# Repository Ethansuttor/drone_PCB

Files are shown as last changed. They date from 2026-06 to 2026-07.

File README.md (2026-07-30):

# Custom Drone Flight Controller PCB

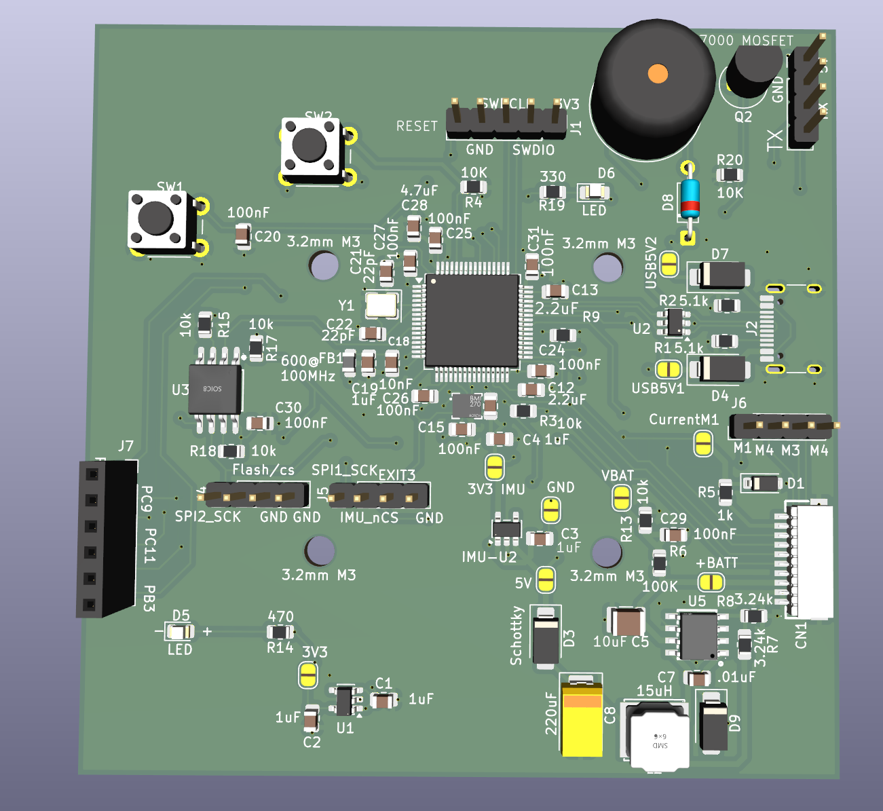
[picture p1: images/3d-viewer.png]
Flight controller PCB, top view


An 80×80 mm STM32F405 flight controller for a 4S freestyle quad, running Betaflight off a custom target I wrote. I built it to find out whether I could take an embedded system from a blank schematic all the way to something that actually flies.

Boards are at JLCPCB. Nothing has been powered on yet, so treat everything below as designed-and-verified-on-paper, not proven.

There's no VTX, camera, or OSD. Those are solved problems, and adding them would have cost layout time I wanted to spend on power architecture, IMU integration, and getting the pinout right.

## Why it looks like this

The biggest constraint was self-imposed: the board has to mate with an ESC I already owned, a Flycolor Raptor BLS-04 4-in-1, using its existing 10-pin harness. That turned out to be the most useful decision I made, because the BLS-04 has no BEC. It hands you raw pack voltage and nothing else. So the board needs its own buck converter running off 16.8 V, which is a much more interesting problem than accepting a regulated 5 V from somewhere else.

The board is oversized on purpose. 80×80 mm with a standard 30.5 mm mounting pattern means it overhangs the stack, which would be silly on a real build. But everything is on the top layer in one hotplate reflow pass, and I hand-place all of it, so the extra room is worth more to me than the elegance.

The STM32F405 was the easy call — native Betaflight support, and writing the custom target is a big chunk of the point.

## Hardware

- MCU: STM32F405RGT6, 168 MHz Cortex-M4F, LQFP-64
- IMU: Bosch BMI270 on SPI1
- Blackbox: GigaDevice GD25Q16E, 2 MB SPI NOR on SPI2
- Input: 4S LiPo, 14.8 V nominal / 16.8 V charged, through the ESC harness
- Buck: TPS5450DDAR, VBAT to 5 V
- Regulators: AP2112K-3.3 for MCU/flash/logic and the IMU's VDDIO; TLV733P-3.3 as a separate quiet rail feeding only the IMU's VDD
- Receiver: FlySky FS-iA6B on i-BUS into UART1
- USB-C for Configurator and DFU
- 4-layer: signal / solid ground / power / signal, ENIG finish
- Spare UART3, USART6 and I2C1 pads for GPS or a mag later

## The parts that went wrong

This is the section I'd actually want to talk about in an interview.

**The IMU disappeared mid-design.** I'd settled on a TDK ICM-42605. Then the entire 426xx family went reel-only at LCSC — minimum orders of a thousand-plus — and out of stock at DigiKey and Mouser. In single quantities it simply stopped existing. The replacement was a Bosch BMI270, which shares the 2.5×3.0 mm LGA-14 outline and nothing else: completely different pinout, new footprint, every IMU net re-routed, different decoupling.

What saved it was a decision I'd made months earlier for unrelated reasons. Splitting the 3.3 V rail in two — a main AP2112K for logic and a dedicated TLV733P for the gyro — meant VDD was already isolated from switching noise. When the part changed, VDD still landed on the quiet rail and VDDIO still landed on the logic rail. A forced sourcing change cost me a footprint and a re-route instead of a power redesign. I'd like to claim I planned for that. I didn't.

The tradeoff is real, though: the BMI270 ships uncalibrated, which is why Betaflight discourages it for new designs, and it caps the PID loop at 3.2 kHz instead of 8 kHz. For Acro freestyle neither matters much. It's still a downgrade I took because the alternative was not building the board.

**I ordered the wrong flash chip.** The BOM called for a 128 Mbit part. A 16 Mbit part arrived — 2 MB instead of 16. I found it a week after the boards shipped, while cross-checking three different BOM files against the firmware, which is a sentence that should tell you something about how I was managing the BOM.

I'm keeping it. Betaflight identifies SPI NOR by JEDEC ID at runtime, and the GD25Q16E is already in the driver's device table, so nothing changes in firmware. What I lose is log duration: about 22 seconds at full rate, or roughly 90 seconds if I drop the blackbox sample rate to 1/4. Since 800 Hz still resolves everything below 400 Hz, where the noise peaks that matter for filter tuning live, and since tuning runs are a minute anyway, the practical cost is that I can't log a whole pack. Every candidate chip shares the same SOIC-8 208-mil footprint, so fixing it later is a hot-air swap.

**A DMA collision moved a motor output.** Motor 4 originally sat on PB7, which wanted DMA1 Stream 3 — the same stream SPI2_RX uses for the blackbox flash. DShot would have fought the logger for it. The final as-built mapping is M1 = PB0 and M2 = PB1 on TIM3, M3 = PA3 and M4 = PB10 on TIM2, checked against RM0090's DMA request mapping table. I'll confirm it with `dma show all` at bring-up rather than trusting the table twice.

## Designed so I can actually bring it up

I assume I've made mistakes I haven't found yet, so the board is built to fail safely and be diagnosed.

Four normally-open solder jumpers split the power tree: buck output to the 5 V rail, 5 V to each LDO, and the quiet 3.3 V rail to the IMU. Each stage comes up on a current-limited bench supply before the next jumper is closed, so a short behind one jumper can't take the STM32 with it.

Test points sit on every rail plus multiple grounds, on the buck's switch and feedback nodes for scoping, and on both ADC sense lines for calibration. There are dedicated ground loops next to the buck and the IMU so a scope probe gets a short ground lead instead of the usual six inches of alligator clip.

Unused STM32 pins are broken out to a labelled header where the layout allowed — timer-capable pins for motor reassignment, a spare UART, spare ADC channels, and SWO. Cheap insurance against a pin-level mistake that would otherwise mean a respin.

One more thing that isn't a jumper: the schematic numbers the ESC connector in the reverse order to the manufacturer's diagram. It's only correct if the connector mates flipped. Before anything gets powered, I continuity-beep VBAT and both grounds from the mated cable to the ESC's XT60. Get that wrong and 16.8 V lands on a 3.3 V GPIO.

## Where it's at

Boards ordered from JLCPCB on 2026-07-19, roughly two weeks out. Bare 4-layer with a frameless top-side stencil, quantity 5. ENIG, mostly so the LGA gyro and the fine-pitch parts solder predictably.

Schematic and layout are done, ERC and DRC both clean. The custom Betaflight target builds. Two BOM questions are still open — whether the TPS5450 or the older TPS5430 actually shipped, and whether the buck inductor is the 15 µH the TI worked example calls for or the 22 µH left over from when this was a 6S design. Both get resolved with a multimeter and a magnifier before I populate anything.

## Next

Paste, populate, hotplate. Then staged bring-up through the jumpers, rail smoke tests, SWD in to flash the target, and motor spin tests with props off. Calibrating the voltage and current ADC scales comes last, since neither is knowable until I can measure them.

Then I find out what I got wrong.

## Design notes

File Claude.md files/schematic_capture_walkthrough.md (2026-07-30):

# Schematic Capture Walkthrough — Drone FC v3

Companion to `drone_fc_project_context_v3.md`. Follow this block by block in KiCad's schematic editor (Eeschema). Capture in this order — power first, MCU core next, peripherals last — so the rails and grounds exist before you hang anything off them.

## KiCad shortcuts you'll use constantly
- `A` — add symbol · `P` — add power symbol · `W` — draw wire · `L` — place net label
- `Q` — place no-connect (×) flag on unused pins · `E` — edit selected symbol/value · `V` — edit value
- `R` rotate · `M` move · `G` drag (keeps wires attached)
- Wires connect by **net name** even without a physical line — use net labels (`L`) liberally instead of dragging long wires across the sheet. Two pins with the same label = same net.

## Global conventions for this board
- **Three supply rails**, each its own power symbol: `+5V`, `+3V3`, `+3V3_IMU`. Grounds all tie to one `GND`.
- Put **decoupling caps physically next to the pin** they serve in layout — but in the schematic just label them clearly (e.g. `C_VDD1`).
- Every power *input* the board generates needs a **PWR_FLAG** (Eeschema → place it on `+5V`, `+3V3`, `+3V3_IMU`, and `GND` once each) or ERC will complain the rails are "driven by nothing."

---

## Capture progress (2026-06-26)
| Block | Status |
|---|---|
| 1 — Onboard buck (TPS5430) | **Done** — fully wired (VIN/Cin, PH+inductor, catch diode, BOOT cap, FB divider, Cout) |
| 1 — USB OR Schottky | **Done** (VBUS→+5V) |
| 2 — Both LDOs (AP2112K + TLV733P) | **Done** — both rails wired |
| 3 — MCU core | Power-in / decoupling reviewed & corrected (caps shunt rail→GND, VDD pins tap +3V3 directly). Clock/boot/SWD still to wire |
| 4 — USB-C | Receptacle (14P symbol), CC pulldowns, Schottky, D±, ESD placed. **Fix outstanding:** USBLC6-2 pin 2→GND and pin 5→VBUS were left floating |
| 5 — ESC connector **J10** | Placed; **VBAT + GND wired, signal/logic lines NOT yet** (M1–M4, CRT current, ESC_TLM) + their ADC protection |
| 6 — IMU power | **Done** (VDD, VDDIO, grounds, RESV, INT2). **IMU SPI logic NOT yet** (SCK/MISO/MOSI/CS/INT) |
| 7 — Flash | Not started |
| 8 — Receiver header / spares | Header placed; logic confirmed (FlySky i-BUS) |
| 9 — Buzzer / LED | Not started |
| 10 — ERC / footprints | Pending |

**Next up:** IMU SPI1 logic lines, J10 signal lines + ADC protection, MCU clock/boot/SWD, flash.

---

## Block 1 — Power input: onboard buck + USB ORing
Goal: generate a clean `+5V` rail **on-board** from the battery (the ESC's raw VBAT), ORed with USB, with no backfeed into USB.

> The BLS-04 / Trinx G20 ESCs have **no BEC** — they only pass raw pack voltage. So the FC makes its own 5V, exactly like a commercial stack FC. `VBAT_RAW` arrives on the ESC 10-pin harness (Block 5) and feeds both the VBAT sense divider *and* this buck.

**Buck — TPS5430DDAR** (`drone_lib:TPS5430DDAR`, ESOP-8, C9864). Pinout: 1 BOOT · 4 VSENSE · 5 ENA · 6 GND · 7 VIN · 8 PH · exposed pad = GND.
- **VIN (7)** ← `VBAT_RAW`. Decouple **2×10µF 50V X7R (GRM32ER71H106KA12L, C77102) + 100nF** from VIN→`GND`, right at the pin. *(50V parts — 6S is 25.2V.)*
- **GND (6)** + **exposed pad** → `GND`.
- **PH (8)** = switch node → one end of the **22µH (≥3A) shielded inductor (CKCS6028-22µH, C354622)**; other end → `+5V`.
- **Catch diode — SS34** (`Diode:D_Schottky`): cathode → `PH`, anode → `GND`.
- **BOOT (1)** → **10nF** cap to `PH`.
- **VSENSE (4)** ← feedback divider: **R1 = 10k** from `+5V` to VSENSE, **R2 = 3.24k** from VSENSE to `GND` (Vref 1.221V → 5.0V).
- **ENA (5)** → leave floating (internal pull-up enables it). *(Optional: a VBAT→ENA resistor divider sets a UVLO turn-on threshold.)*
- **Output cap** on `+5V`: **220µF aluminum-polymer (~20–40mΩ ESR) + 100nF** to `GND`. **Not pure ceramic** — the TPS5430 is internally compensated for some output-cap ESR, so an all-ceramic output can ring/oscillate (use polymer or POSCAP).

**USB OR:**
- **Schottky** SS34/B5819W — anode to USB `VBUS` (Block 4), cathode to `+5V`. ORs USB power onto the rail on the bench, blocks backfeed into USB.

Result: `+5V` comes from the onboard buck in flight and from USB through the Schottky on the bench. Drop a **PWR_FLAG** on `+5V` and on `GND`. *(No external 5V-in connector — that's removed.)*

**Layout note:** keep the buck loop (VIN cap → IC → inductor → catch diode → output cap) tight, the PH switch node small, and the whole thing **away from the IMU and the VBAT/CRT ADC traces**.

## Block 2 — 3.3V rails (two LDOs)
**Main 3.3V — AP2112K-3.3 (C51118, SOT-23-5):**
- VIN ← `+5V`, GND ← `GND`, VOUT → `+3V3`, EN → tie to VIN (`+5V`) so it's always on.
- Input caps: 10µF + 100nF from VIN to GND. Output caps: 10µF + 100nF from VOUT to GND.

**Quiet IMU 3.3V — TLV733P-3.3 (C134139, SOT-23-5):**
- VIN ← `+5V`, GND ← `GND`, VOUT → `+3V3_IMU`, EN → tie to VIN.
- Caps: 1µF in, 1µF out (plus the 100nF that sit at the IMU pins in Block 6).

Drop **PWR_FLAG** on `+3V3` and `+3V3_IMU`. The IMU rail is deliberately separate from everything else for low gyro noise.

---

## Block 3 — STM32F405RGT6 core (the big one)
Place symbol **`MCU_ST_STM32F4:STM32F405RGTx`** (`A`, type STM32F405). Wire its support circuitry:

**Power pins**
- All `VDD` pins → `+3V3`; all `VSS` pins → `GND`. LQFP-64 has four VDD/VSS pairs — put a **100nF next to each** plus one **4.7µF bulk** on `+3V3` near the chip.
- `VDDA` → `+3V3` through the analog filter: **1µF + 10nF** to GND at the pin (optionally a ferrite/small resistor from +3V3 to VDDA). `VSSA` → `GND`.
- `VBAT` pin → `+3V3` with a **100nF** to GND (not using a coin cell; just tie to 3V3).

**VCAP (mandatory — core regulator)**
- `VCAP_1` (pin 31) → **2.2µF X5R/X7R** to GND, placed at the pin.
- `VCAP_2` (pin 47) → **2.2µF X5R/X7R** to GND, placed at the pin.
- Skip these and the chip won't boot reliably.

**Clock (HSE)**
- 8MHz crystal between `PH0`/`OSC_IN` and `PH1`/`OSC_OUT`.
- One load cap from each crystal pin to GND. **Value 22pF** (open item: confirm against the crystal's CL — 22pF suits CL ≈ 12–14pF).

**Boot / reset**
- `BOOT0` → **10k pull-down to GND**, plus a tact switch from BOOT0 to `+3V3` (press = enter DFU).
- `PB2/BOOT1` → **10k pull-down to GND** (must be low for system-memory DFU; floating = unreliable boot).
- `NRST` → tact switch to GND + **100nF** to GND.

**SWD programming header**
- 5-pin header (`Conn_01x05`): `+3V3`, `PA13`/SWDIO, `PA14`/SWCLK, `NRST`, `GND`. Leave PA13/PA14 otherwise unassigned.

---

## Block 4 — USB-C (wired; one ESD fix outstanding)
Place **USB-C receptacle** — schematic uses the KiCad `USB_C_Receptacle_USB2.0_14P` symbol (maps to the TYPE-C-31-M-12, C165948). The 14P is USB-2.0-only and omits the SBU pins, which is correct — this link is only a USB-2.0 device port for DFU + Betaflight config.

- **Reversible-pin shorting:** tie the two `D+` positions together (A6 + B6) and the two `D−` together (A7 + B7) at the connector — Type-C is reversible, so each line is duplicated.
- `VBUS` (A4) → the Schottky anode in Block 1. Tie all VBUS/GND positions on the connector together; don't leave duplicates floating.
- `GND` / shield pins → `GND`.
- `CC1` (A5) → **5.1k to GND**. `CC2` (B5) → **5.1k to GND** (Rd — tells the host this is a device/sink; without these no VBUS).
- `D+` → MCU `PA12`, `D−` → MCU `PA11`. **No series resistors** (F405 has internal impedance per AN4879).
- **ESD — USBLC6-2SC6 (C7519, SOT-23-6)**, placed right at the connector. Force the trace *through* it by renaming across it: connector side `USBC_DP`/`USBC_DM` → device side `USB_DP`/`USB_DM`. Pairing: I/O1 = pins 1 (connector) & 6 (MCU); I/O2 = pins 3 (connector) & 4 (MCU).
  - **FIX OUTSTANDING:** **pin 2 → `GND`** and **pin 5 → `VBUS`** must be connected — they were left floating, which disables the clamp (the steering diodes need both rails). Wire these before ERC.
- **Optional VBUS sense:** 10k/10k divider from `VBUS` to `PC0` (Betaflight `USB_DETECT_PIN`).

## Block 5 — ESC connector **J10** (verified pinout — handle VBAT/CRT with care)
Place the **JST SH 1.0 10-pin** (SM10B-SRSS-TB, C160409, `drone_lib`). **Status (2026-06-26): VBAT + GND wired; signal lines (M1–M4, CRT, ESC_TLM) + their ADC protection still TODO.** Wire per the **verified** table:

| ESC pin | Net | MCU | Protection on the FC side |
|---|---|---|---|
| TX (telemetry) | `ESC_TLM` | `PC7` (USART6 RX) or leave NC | none — non-functional on BLHeli_S |
| CRT (current) | `CURR_SENSE` | `PC2` | **1kΩ in series + 3.3V Zener from PC2 to GND** |
| S1 | `M1` | `PB0` | — |
| S2 | `M2` | `PB1` | — |
| S3 | `M3` | `PA3` | — |
| S4 | `M4` | `PA2` | — |
| NC | — | — | place a no-connect `Q` |
| VBAT | `VBAT_RAW` | `PC1` | **100kΩ/10kΩ divider → PC1, + 100nF from PC1 to GND** |
| GND | `GND` | — | — |
| GND | `GND` | — | — |

- **VBAT divider:** 100k from `VBAT_RAW` to node, 10k from node to GND, node → `PC1`, 100nF node→GND. This scales up-to-25.2V down to ~2.3V max. Without it you put pack voltage on a 3.3V pin.
- **`VBAT_RAW` also feeds the onboard buck (Block 1):** the same harness VBAT net runs to the TPS5430 VIN. The FC's current draw is small, so the harness VBAT line carries it fine — this is how the FC is powered in the air now that the external BEC is gone.
- **Current clamp:** 1k from `CRT` to `PC2`, then a 3.3V Zener from `PC2` to GND. The 1k limits fault current into the clamp.
- Motor nets `M1–M4` go straight to the timer pins; you'll remap S1–S4 order in Betaflight, so exact assignment isn't critical.

---

## Block 6 — IMU (Bosch BMI270) — **DONE** (re-done 2026-07-30, was ICM-42605)

Place **BMI270** (C2836813, `drone_lib`), footprint `LGA-14_L3.0-W2.5-P0.50-BR`.
Datasheet pin map (rev 1.3 Table 22, p.145): 1 SDO · 2 ASDx · 3 ASCx · 4 INT1 ·
5 VDDIO · 6 GNDIO · 7 GND · 8 VDD · 9 INT2 · 10 OCSB · 11 OSDO · 12 CSB ·
13 SCx · 14 SDx.

> ⚠ **Do not reuse the 426xx wiring from an earlier revision of this doc.** The
> BMI270 shares only the package *outline* — pin functions are completely
> different, and two of the old habits are now actively wrong (see the strapping
> bullet below).

**Power — split rails, unchanged from the 42605 design:**
- `VDD` (pin 8) → **`+3V3_IMU`** (quiet TLV733P rail, via **JP10**), **100nF** at the pin. Noise-sensitive analog/MEMS supply. Range 1.71–3.6V.
- `VDDIO` (pin 5) → **`+3V3`** (main logic rail — NOT the quiet rail), **100nF** at the pin. Carries digital I/O switching noise and sets the SPI logic level, so it rides the host rail. Range 1.2–3.6V.
- **Decoupling is 100nF × 2 only** — the 2.2µF/0.1µF/10nF arrangement was a 426xx datasheet requirement and does not apply.
- `GNDIO` (6) and `GND` (7) → `GND`.

**Unused-pin strapping — different from the 42605, get this right:**
- `ASDx` (2) and `ASCx` (3) → **`VDDIO`**. Datasheet note ** is explicit: if the secondary interface is unused these may go to VDDIO or be left open, but **do not connect to GND**. (The 42605's RESV-to-GND habit would be a mistake here.)
- `INT2` (9), `OCSB` (10), `OSDO` (11) → **do not connect**. Note *** allows OCSB/OSDO to GND only if `IF_CONF.ois_en = 0`; leaving them open is safer.
- There is **no** mandatory-ground RESV pin on this part.

**SPI1 logic:**
- `SCx` (13) → `PA5`, `SDO` (1) → `PA6`/MISO, `SDx` (14) → `PA7`/MOSI.
- `CSB` (12) → `PC4`, **plus a 10k pull-up to `+3V3`** (= VDDIO). Holds CS high through boot/DFU. Note the pull-up is to the *host* rail, matching the SPI logic level.
- `INT1` (4) → `PC3` (EXTI3) — keep this trace short in layout.
- **SPI clock ≤10MHz** for the BMI270 (Betaflight's `BMI270_MAX_SPI_CLK_HZ`). This is a real tightening from the 42605's 24MHz — the old "/4 = 21MHz" advice is no longer valid.
- Protocol note: the BMI270 powers up in **I2C** mode and only switches to SPI after seeing a **rising edge on CSB** (datasheet §"protocol selection"). The 10k pull-up holds CSB high through POR; Betaflight's driver toggles CS to make the transition. Only matters if you drive the chip from bare STM32 code.
- Layout note (not schematic): IMU dead-center, axes aligned to the frame, solid ground under it.

## Block 7 — Blackbox flash (SPI2) — **as-fitted part is GD25Q16E, 2 MB**
Place **GD25Q16E** (C2904431, SOIC-8 208mil). Powered from `+3V3`.

> ⚠ **Two corrections vs. earlier revisions of this doc:**
> 1. The part is **not** a W25Q128JVSIQ (C97521, superseded on MOQ) and **not**
>    the BY25Q128ESSIG the BOM specified. The chip actually ordered and fitted is
>    a **GigaDevice GD25Q16E — 16 Mbit = 2 MB, one eighth the intended capacity.**
>    Kept deliberately; see `VERIFIED_PINOUT.md` § Blackbox flash.
> 2. **MISO is on `PC2`, not `PB14`.** The old line below was wrong and is
>    contradicted by the as-built schematic.

- `VCC` → `+3V3` with **100nF**. `GND` → `GND`.
- SPI2: `CLK` → `PB13`, `DO`/MISO → **`PC2`**, `DI`/MOSI → `PB15`.
- `CS` → `PB12`.
- `/WP` and `/HOLD` → tie to `+3V3` (disabled) unless you have a reason not to.
- Footprint is SOIC-8 208mil, shared by every candidate part (W25Q128, BY25Q128ES,
  GD25Q16E, GD25Q128E) — so a capacity upgrade is a hot-air swap, no layout change.
- Betaflight needs no code change for the 2 MB part: `USE_FLASH_W25Q128FV` only
  gates the generic `m25p16` driver, which detects by JEDEC ID at runtime.

---

## Block 8 — Receiver header & spare pads
- **Receiver header** (4-pin `Conn_01x04`): `+5V`, `GND`, `TX`=`PA9` (UART1 TX), `RX`=`PA10` (UART1 RX). **Receiver = FlySky FS-iA6B → use i-BUS** (single serial wire on UART1 RX). i-BUS is non-inverted, so it connects straight to RX — **no inverter needed**. *(Reject S.BUS: it's inverted and the F405 has no internal UART inverter — would need an external transistor.)* PA10 is a 5V-tolerant (FT) pin, good since the iA6B is powered at 5V. TX pin is for optional i-BUS telemetry later. Betaflight: Serial RX on UART1, provider = IBUS. **Power pin = 5V** (iA6B input range 4.0–8.4V; never battery). One 3-wire run (5V/GND/RX) to the receiver's i-BUS port both powers it and carries data.
- **Spare UART3 pads:** `PB10` (TX), `PB11` (RX) — future GPS/MSP.
- **Spare USART6 pads:** `PC6` (TX), `PC7` (RX) — note PC7 may also carry the ESC `ESC_TLM` net if you wired it in Block 5; pick one use.
- **Spare I2C1 pads:** `PB6` (SCL), `PB7` (SDA) — future baro/mag. Add 4.7k pull-ups to `+3V3` on each if you expect to use them.

## Block 9 — Buzzer & status LED
**Buzzer (hand-soldered, DNP in JLC BOM):**
- `PC5` → gate of **2N7002** (via the gate; source to `GND`).
- Buzzer `+` pad → `+5V`; buzzer `−` pad → 2N7002 drain. Place **1N4148 flyback** across the buzzer (cathode to +5V, anode to drain).
- Use the SUN-12095 footprint (C360615) for the pads but mark the buzzer **DNP** so JLC skips it.

**Status LED:**
- `PB8` → **330Ω** → LED anode; LED cathode → `GND` (or wire active-low to +3V3 if you prefer — just be consistent in config). Avoid PC13 (forbidden — power-switch domain).

---

## Block 10 — Finish & check
1. **Place PWR_FLAGs** (once each) on `+5V`, `+3V3`, `+3V3_IMU`, `GND` if not already.
2. **No-connect (`Q`)** every genuinely unused MCU pin and the ESC `NC` pin, or ERC will warn.
3. Run **Inspect → Electrical Rules Checker (ERC)**. Resolve real errors (unconnected pins, conflicting outputs). Expect a few "unconnected" warnings on spare pads — those are fine to leave or no-connect.
4. **Annotate** (assign reference designators) and **assign footprints** (Tools → Assign Footprints): your `drone_lib` parts already carry footprints; assign standard 0402/0603 footprints to passives and attach their LCSC part numbers in the symbol's field (this drives the JLC BOM later).
5. Save, commit to your `.history` git, and only then move to PCB layout.

## Order of attack (so grounds/rails exist first)
Power (1–2) → MCU core + VCAP + clock + boot (3) → USB-C (4) → ESC connector + ADC protection (5) → IMU (6) → flash (7) → headers/spares (8) → buzzer + LED (9) → ERC (10).

## Watch-outs
- VCAP caps and the VBAT-pin 100nF are easy to forget and both cause "won't boot" symptoms.
- The VBAT divider and CRT Zener are safety-critical — never wire ESC VBAT/CRT straight to a GPIO.
- IMU rails are split on purpose: **`VDD` (pin 8) on `+3V3_IMU`** (quiet), **`VDDIO` (pin 5) on `+3V3`** (host logic rail). Don't put VDD on the main rail or VDDIO on the quiet rail.
- **USBLC6-2 pin 2 → `GND`, pin 5 → `VBUS`** — if either floats the ESD array does nothing (caught this in the draft).
- Single ground only — there is no separate "digital"/"power" GND net. Everything returns to one `GND` pour (L2); isolation is by split *power* rails + layout, not split grounds.
- Receiver header power pin = **5V**. Use the 5V-tolerant RX pin (PA10) for the i-BUS signal.
- Buck **input caps must be ≥50V** (6S = 25.2V); keep the buck switch node/loop tight and away from the IMU and ADC lines, or it shows up as gyro noise.
- The FC has **no external 5V input anymore** — power comes from `VBAT_RAW` (ESC harness) through the onboard TPS5430 buck.

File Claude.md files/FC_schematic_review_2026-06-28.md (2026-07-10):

# Schematic Error Review — Drone FC (2026-06-28)

**Scope:** schematic only, pre-layout. **Method:** geometric netlist extracted from the `.kicad_sch` s-expressions (pin coords transformed by each symbol's rotation/mirror, unioned with wires/junctions/global-labels/power-symbols). Calibrated transform: 190/227 pins land on a connection point; power/VCAP/USB/SPI all resolve correctly, so connectivity is reliable. Pin functions re-checked against DS8626 (STM32F405 LQFP-64), the ICM-42605 and TPS5430 datasheets.

> **Source-of-truth note:** the working files in `Drone_PCB_FC/` are **corrupt** (see #0). This review was run on the newest intact backup: `Drone_PCB_FC-backups/Drone_PCB_FC-2026-06-27_204112.zip` (2026-06-27 20:41 local) — which is *newer* and more complete than the corrupted working copy.

---

## 0. FILE CORRUPTION — fix before anything else
`MCU-STM32F405.kicad_sch` and `LDOs.kicad_sch` on disk are **truncated mid-write** (unbalanced parens — MCU ends mid-`C13` property). The other sheets are intact but **NUL-padded**. The stale `~*.lck` files (dated Jun 25) mean KiCad exited ungracefully and a save got mangled (looks like a sync/crash). The working `.kicad_sch` files also carry an *older* mtime (11:42) than the latest backups (through 20:41), so they're both corrupt **and** stale.

**Fix:** Don't fab or ERC from the working folder as-is. Open the project in KiCad — if it loads clean, immediately `File → Save` (overwrites the corruption). If it errors on load, restore from `Drone_PCB_FC-2026-06-27_204112.zip`. Nothing newer than 20:41 was lost (the corrupt files are older content).

---

## CRITICAL / safety

### C1 — ESC connector CN1 is wired in REVERSE pin order vs your verified harness table  ⚠️ 25 V-onto-GPIO risk
Extracted CN1 signal pins (1→10): `GND, GND, +BATT, NC, M4(TIM4_CH2), M3(TIM4_CH1), M2(TIM3_CH4), M1(TIM3_CH3), CURR, NC`. (Pins 11/12 = shield → GND, fine.)
Your `schematic_capture_walkthrough.md` Block 5 table says pin1=TX, pin2=CRT, pin3=S1 … **pin8=VBAT**, pin9/10=GND. The schematic is that table **flipped end-for-end** — VBAT sits on CN1 pin 3, and a motor GPIO (PB0) sits on CN1 pin 8.

This is only correct if your ESC cable is a **reversed/crossover** SH1.0 type (or the footprint's pin-1 pad is at the far end). With a **straight 1:1 cable** + same-handed footprint, harness VBAT (ESC pin 8, up to **25.2 V** on 6S) lands on **CN1 pin 8 = PB0 = TIM3_CH3**, a 3.3 V GPIO → **instant MCU death**. Also CRT and TX would short to GND.

**This cannot be settled from the schematic.** Resolve it two ways, both:
1. Make the schematic match your documented intent (TX on pin 1 … VBAT on pin 8), *or* explicitly confirm the footprint pin-1 + reversed cable and update the Block-5 table so it's not contradictory.
2. **Before first power-up** do the continuity beep test (open item #1): VBAT + both GNDs from the *mated cable* to the ESC XT60 pads.

### C2 — Current-sense line has NO protection (required) and is on the wrong ADC pin
`CURR` net = `{CN1.9, U4.9/PC1}` only. The ESC CRT output runs **straight into PC1 (ADC123_IN11)** — no 1 kΩ series resistor, no 3.3 V Zener clamp. Your context doc marks "1 kΩ series + 3.3 V Zener clamp (**required**)" on this line; the walkthrough put it on PC2. Neither part exists in the netlist (no 1 kΩ R, no Zener anywhere in the BOM).
**Fix:** insert 1 kΩ in series CN1.9→ADC, add a 3.3 V Zener (or 3.3 V TVS) from the ADC node to GND, + ~100 nF. Pick PC1 *or* PC2 and set it in the target; PC2 is currently free.

### C3 — No VBAT voltage-sense divider exists (no battery voltage telemetry)
`+BATT` = `{CN1.3, U5.7 (buck VIN), C5.1}` — battery reaches the buck only. There is **no 100k/10k divider to any ADC pin** (PC0 and PC2 are free, both unconnected). Betaflight will have current sense but **no pack-voltage reading** → no voltage alarms, no sag compensation.
**Fix:** add 100 kΩ/10 kΩ from `+BATT` to a free ADC pin (PC0 = ADC123_IN10, or PC2) + 100 nF to GND. 100k/10k → 2.29 V at 25.2 V, safe; set `vbat_scale ≈ 110`.

---

## MAJOR / functional

### M1 — IMU VDD / VDDIO rails are SWAPPED (defeats the dedicated quiet LDO)
Extracted: `U6.8 VDD → +3V3` (main/noisy), `U6.5 VDDIO → +3V3_IMU` (quiet TLV733P). Decoupling follows the wrong rails (C10 2.2 µF + C11 0.1 µF on VDD/main; C9 10 nF on VDDIO/quiet).
This is **backwards from your own locked decision** (context v3, 2026-06-26: "VDD (pin 8) stays on the quiet +3V3_IMU … VDDIO (pin 5) now sits on the main +3V3"). Per the ICM-42605 datasheet, **VDD** is the device/MEMS/analog supply (the noise-sensitive one); **VDDIO** is just digital-I/O level. As drawn, the gyro's analog supply rides the shared MCU/flash rail and the clean LDO is wasted on the I/O pin → worse gyro noise floor.
**Fix:** swap the rails — VDD (pin 8) + C10 + C11 → `+3V3_IMU`; VDDIO (pin 5) + C9 → `+3V3`. (Also move the CS pull-up R3 to match VDDIO's rail.)

### M2 — Buck inductor value mismatch: schematic 15 µH vs locked BOM part 22 µH
`L2 = 15 µH` (symbol `Device:L_Iron`). Your locked BOM inductor is **22 µH, CKCS6028-22µH, LCSC C354622**. 15 µH is electrically valid (TPS5430 datasheet design example uses 15 µH, KIND=0.2, L_min≈12.5 µH; for 5 V/3 A/6S L_min≈13 µH), but the **schematic value and the part you'll order disagree** — the generated BOM would call out 15 µH.
**Fix:** set `L2 = 22 µH` to match C354622 (lower ripple, gentler), or re-spec the BOM to a 15 µH ≥3 A shielded part. Either way reconcile. (`L_Iron` is just a cosmetic symbol — assign the real shielded-inductor footprint.)

### M3 — Motor 4 (PB7/TIM4_CH2) DMA collides with blackbox SPI2_RX
Motors map PB0=TIM3_CH3 (DMA1 S7), PB1=TIM3_CH4 (S2), PB6=TIM4_CH1 (S0), **PB7=TIM4_CH2 (DMA1 S3)**. Flash SPI2_RX is also **DMA1 Stream 3** (RM0090 Table 42). They can't both run a DMA at once. Usually survivable (blackbox *writes* use SPI2_TX/S4; log download happens disarmed), but it constrains the custom target and can break DMA flash reads while armed.
**Fix (clean, optional):** move motor 4 to **PB5 = TIM3_CH2 (DMA1 S5)** — conflict-free vs all other motors, SPI2 and SPI1. PB5 is currently free.

---

## COMPLETENESS — the schematic is not finished
These blocks from your walkthrough are simply not in the netlist yet. Don't start layout until they're in, or you'll re-spin:

- **No SWD header.** PA13/PA14 dangle on unnamed stub nets; no `Conn` for SWD exists. You'd be DFU-only with no debugger. Add the 5-pin header (3V3/SWDIO PA13/SWCLK PA14/NRST/GND). *(Block 3)*
- **No buzzer circuit.** PC5 is a bare stub — no 2N7002, no buzzer pads, no 1N4148. *(Block 9)*
- **No status LED.** PB8 is a bare stub — no LED, no 330 Ω. *(Block 9)*
- **No spare UART3/USART6/I2C1 pads** (PB10/PB11, PC6/PC7, PB6/PB7). Optional, but they were in the plan. *(Block 8)*

## HOUSEKEEPING / BOM hygiene

- **`C1` value = `C1uF`** (malformed) → set to `1uF`. *(LDOs)*
- **`Y1` value = `Crystal_GND24`** (symbol name, not a value) → set `8 MHz` and assign a real crystal + confirm CL vs the 22 pF load caps (open item #2). *(MCU)*
- **`D3`/`D4` value = `D_Schottky`** (generic) — these are the USB-OR diodes; assign a real part (SS34/B5819W). *(LDOs)*
- **Battery-rail cap ratings unspecified.** `C5` (10 µF on +BATT) and any +BATT ceramic must be **≥50 V for 6S** (25.2 V). Plan called for **2×10 µF**; only one (C5) is placed. Add a 100 nF HF cap at VIN. `C8` (220 µF out) needs ≥10 V; it's correctly a polymer (`C_Polarized`) — keep it non-ceramic for TPS5430 loop stability.
- **Many unused MCU pins** sit on unnamed nets — add no-connect (`Q`) flags or ERC will bury real errors in warnings.
- **5 V rail is actually ~4.6 V:** both the buck (+5V_Buck) and USB (+5V_USB) feed +5V through Schottkys (D3/D4), so the receiver/buzzer see ≈4.6 V. Fine (FS-iA6B wants 4.0–8.4 V), just be aware. FB correctly taps +5V_Buck (pre-diode), so the buck still regulates a true 5.0 V.

---

## Already CORRECT / fixed since the 2026-06-27 review (don't re-touch)
- **VDDA** now properly filtered: `+3V3 → FB1 (600 Ω) → VDDA`, C18 (10 nF) + C19 (1 µF) VDDA→GND. (The old VDDA-to-GND short is gone.)
- **Both VCAP caps present:** C12 (2.2 µF) on VCAP_1, C13 (2.2 µF) on VCAP_2, each to GND.
- **Buck feedback R8 = 3.24 kΩ** (was the dangerous bare "3.24"); Vout = 1.221·(1+10k/3.24k) = 5.0 V. ✓
- **Receiver J3 wired:** Pin3→UARTx_RX→PA10, Pin4→UARTx_TX→PA9, Pin1→+5V, Pin2→GND (USART1, non-inverted i-BUS). ✓
- **USBLC6-2 fixed:** pin 2→GND, pin 5→VBUS(+5V_USB); D±routed *through* the array to PA11/PA12. ✓
- **VDD decoupling:** 4×100 nF (C24–C27) + 4.7 µF (C28) for the four VDD pins; VBAT pin1→+3V3. ✓
- IMU SPI1 (PA5/6/7, CS=PC4 + R3 pull-up, INT=PC3), flash SPI2 (PB12–15), crystal on PH0/PH1 w/ 22 pF, BOOT0/BOOT1/NRST straps — all correct.

---

## Verdict: **Proceed with changes — do not start layout yet**
The power core, MCU support, USB, SPI buses, clock and boot straps are clean, and the three old fab-blockers are fixed. But: **C1 (ESC pin-order / VBAT-on-GPIO)** is a genuine brick-the-board risk that must be resolved + continuity-verified, **C2/C3** leave required ADC protection and battery sensing missing, **M1** (IMU rail swap) wastes your quiet LDO, and the board is **functionally incomplete** (no SWD/buzzer/LED). Fix C1–C3 and M1–M2, finish the missing blocks, restore the file from backup, then run ERC and re-check before layout.

**Order:** #0 file restore → C1 → C2 → C3 → M1 → M2 → SWD/buzzer/LED → BOM values → ERC.

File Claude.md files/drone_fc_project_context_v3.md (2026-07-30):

# Custom Drone Flight Controller PCB — Project Context v3

**Date:** 2026-06-09. Supersedes v1 (`drone_fc_project_context.md`) and the lost v2. Incorporates the June 2026 audit (`FC_audit_2026-06-09.md`). Build is a **bench/resume project: no VTX, camera, or OSD**.

> ### ⚠ Update 2026-07-30 — IMU CHANGED: ICM-42605 → Bosch BMI270
>
> **Every ICM-42605 / ICM-42688-P / 426xx reference below this box is superseded.**
> The board is built around the **Bosch BMI270** (U7, LCSC C2836813, footprint
> `drone_lib:LGA-14_L3.0-W2.5-P0.50-BR`). The 2026-06-23 decision recorded below
> ("BMI270 evaluated and rejected", "stay with the ICM-42605 default") was
> **reversed on sourcing grounds**: the entire TDK 426xx family went reel-only
> (MOQ 1000+) or out of stock in single quantities at LCSC, DigiKey and Mouser.
>
> It is **not a drop-in.** Same 2.5×3.0mm LGA-14 outline, completely different
> pinout → new footprint and every IMU net re-routed. Decoupling is simpler:
> **100nF at VDD + 100nF at VDDIO**, not the 2.2µF/0.1µF/10nF the 426xx wanted.
> The unused-pin strapping is also different — ASDx(2)/ASCx(3) go to **VDDIO**
> and must *not* be grounded, and INT2(9)/OCSB(10)/OSDO(11) are left
> **unconnected**, where the 42605's RESV pins went to GND.
>
> **The power architecture did not change at all** — VDD still on the quiet
> TLV733P `+3V3_IMU` rail, VDDIO still on the main AP2112K `+3V3`. That's the
> payoff of the rail-split decision: a forced sourcing change cost a footprint
> and a re-route, not a power redesign.
>
> Firmware: Betaflight define is `BMI270`. **PID loop ceiling drops to 3.2 kHz**
> (BF clocks the BMI270 gyro at 3.2 kHz ODR; chip max is 6.4 kHz), SPI clock
> ceiling is **10 MHz** not 24 MHz, and the driver uploads an ~8 KB init blob at
> every boot. The BMI270 also ships uncalibrated — a few percent attitude error
> in Angle/Horizon, irrelevant in Acro. `GYRO_1_ALIGN` must be re-derived.
>
> Canonical pad-by-pad wiring table (verified against BMI270 datasheet rev 1.3
> Table 22, p.145): see **`VERIFIED_PINOUT.md` § IMU**.

**Update 2026-07-11 (SCHEMATIC COMPLETE — verified, entering layout):**
Full netlist re-verified pin-by-pin against the KiCad files (not the docs) this session. Status: **schematic done, ERC-clean pending, ready for layout.** Resolutions since 2026-06-28:
- **IMU rail swap DONE** — as-drawn is now correct: VDDIO (pin 5) → +3V3 (main), VDD (pin 8) → +3V3_IMU (quiet). All 14 ICM-42605 pins verified: MISO/MOSI/SCLK/CS on 1/14/13/12, INT1 (4) → PC3/EXTI3, RESV pin 7 + RESV 2/3/10/11 + INT2/FSYNC (9) → GND, CS 10k pull-up → +3V3. Decoupling: VDD 2.2µF+0.1µF, VDDIO 10nF.
- **Current-sense protection ADDED** — CN1 current pin → R5 1k series → PC1, D1 3.3V zener PC1→GND. Correct clamp (PC1 taps between R5 and zener). **Note: current sense is on PC1** (not PC2 as older pin table said).
- **VBAT divider ADDED** — +BATT → R6 100k → PC2, R13 10k + C29 100nF → GND. Ratio 0.091 (16.8 V → 1.53 V at PC2). Battery telemetry now available; calibrate vbat_scale at bring-up.
- **SWD header ADDED (J1, 5-pin)** — 3V3 / SWDIO=PA13 / SWDCLK=PA14 / GND / NRST. For emergency flash/debug if USB DFU fails.
- **Power LED ADDED** — +3V3 → R14 series resistor → D5 → GND. (Earlier IMU-rail LED D6 removed — do not load the quiet gyro rail.)
- **Buck confirmed complete** — TPS5430, L 15µH, Cin 10µF, Cout 220µF polymer, SS34 catch diode, 10nF BOOT cap, FB 10k/3.24k tied to +5V_Buck output. ENA left floating (TPS5430 enables when floating).
- **ORing diodes D3/D4 verified correct** (anodes at +5V_Buck / +5V_USB sources, cathodes at common +5V).
- **Motor pins confirmed in KiCad**: M1=PB0, M2=PB1, M3=PB6 (TIM4_CH1), M4=PB5 (TIM3_CH2). PA2/PA3/PB7 free.

**⚠ REMAINING BEFORE FAB (physical/process, not schematic):**
1. **ESC connector orientation** — CN1 is numbered reverse vs the manufacturer diagram (VBAT on pad 3, GND pads 1–2, current pad 9). Signal order matches the harness only if the connector mates reversed. **Mandatory: continuity-beep VBAT + both GND pads to the ESC XT60 before first power-up** — a mirror error puts 16.8 V on a 3.3 V GPIO.
2. Run **ERC** to zero before layout (authoritative check for unconnected nets).
3. Buzzer (PC5) and Betaflight status LED (PB8) intentionally not populated — spare UART/I2C pads (PB10/11, PC6/7) not broken out. All optional; add if wanted.
4. **File-sync corruption risk** — keep the project OFF the synced drive or pause sync while editing; a truncated `.kicad_sch` right before Gerber export is the worst-case. Confirm clean saves.

**Update 2026-06-28 (battery → 4S, motor remap, open items):**
- **Battery changed to 4S (14.8 V nominal / 16.8 V full charge)** — was 6S. Consequences: buck output inductor is now **15 µH** (TPS5430 datasheet value for this Vin/Vout; L_min ≈ 12 µH) — **the locked BOM 22 µH part C354622 is superseded; order a 15 µH ≥3 A shielded inductor instead.** Battery-rail/buck-input cap voltage rating requirement relaxes from ≥50 V (6S) to **≥25 V (use ≥35 V for transient margin)**. Any VBAT sense divider scales for 16.8 V.
- **Motor remap (done in schematic):** M4 moved **PB7 → PB5 (TIM3_CH2)** to clear the DMA1-Stream3 clash with SPI2_RX (blackbox). Motors are now M1=PB0/TIM3_CH3, M2=PB1/TIM3_CH4, M3=PB6/TIM4_CH1, M4=PB5/TIM3_CH2 → DMA1 streams S7/S2/S0/S5, all clear of SPI2 (S3/S4). PB7 freed. Verified against RM0090 Table 42.
- **IMU rail swap STILL PENDING in schematic:** as drawn, VDD(pin 8)→+3V3 and VDDIO(pin 5)→+3V3_IMU — **backwards** from the 2026-06-26 decision below. Must swap to VDD(8)→+3V3_IMU (quiet), VDDIO(5)→+3V3 (main). Caps follow their pins (C10 2.2µF + C11 0.1µF on VDD; C9 10nF on VDDIO).
- **Still open (ADC protection):** current sense (PC1) needs **1 kΩ series + 3.3 V Zener** to GND; **add a VBAT divider** (e.g. 100k/10k → free ADC PC0 or PC2, +100 nF) if battery voltage telemetry is wanted.
- **⚠ File corruption:** the working `*.kicad_sch` files keep getting truncated/NUL-padded on save (folder-sync race during KiCad's atomic save). The reliable clean copies are the `Drone_PCB_FC-backups/*.zip`. Fix the sync (pause it while editing, or move the project off the synced drive) and confirm a clean save before fab.

**Update 2026-06-26 (schematic capture in progress):** Buck (TPS5430) **fully wired**; both LDOs (AP2112K + TLV733P) **wired**; USB-C wired; **IMU power wired** (SPI logic still to do); ESC connector **J10** has VBAT+GND wired (signal lines pending). Two decisions refined this session: **(1) IMU rail split** — `VDD` (pin 8) stays on the quiet `+3V3_IMU`, but **`VDDIO` (pin 5) now sits on the main `+3V3`** (host logic rail) so digital I/O switching noise stays off the gyro supply and VDDIO matches the SPI host level. Caps per ICM-42605 BoM: 0.1µF+2.2µF at VDD, 10nF at VDDIO; RESV pin 7→GND mandatory, other RESV + INT2/FSYNC→GND. **(2) Receiver = FlySky FS-iA6B over i-BUS** (non-inverted, straight to UART1 RX; S.BUS rejected — inverted, no internal F405 inverter). Also confirmed: LQFP-64 has **no PDR_ON / no BYPASS_REG** pin (regulator + internal reset always on — nothing to wire); no 32.768kHz LSE needed (Betaflight doesn't use RTC). **Open ESD fix:** USBLC6-2 pin 2→GND, pin 5→VBUS were floating in the draft.

**Update 2026-06-23 (decisions locked):** Board grows to **~60×60mm** (oversized bench board for easy hand assembly; retains 30.5×30.5mm M3 mount to mate the BLS-04). **Assembly changed to self-reflow** — order **bare 4-layer PCBs + frameless stencil** from JLC (not PCBA), keep **all SMD single-sided (top)** for one hotplate pass, leaded (Sn63/Pb37) paste, hot-air station for LGA/rework. **MCU order part = STM32F405RGT6TR** (tape-and-reel/cut-tape, LCSC C15742, 600 in stock, buy-1). **IMU resolved — stay with the ICM-42605 default** (LCSC C2655099, buy-1 cut-tape, ~$9.38, ~1,168 in stock): Betaflight-preferred and shares the LGA-14 426xx footprint, so no design change. **BMI270 rejected** — Betaflight discourages it for new designs (uncalibrated gyro, 5–10% attitude error). ICM-42688-P (C1850418) stays as the drop-in alternate if its reel frees up. **Power architecture changed:** the external Matek MBEC6S is dropped — the FC now carries its **own onboard buck (TPS5430DDAR, C9864, VBAT→5V/3A)** fed from the ESC-harness VBAT, because the BLS-04 / Trinx G20 ESCs have no BEC. The old J5 external-5V-in header is removed.

## Project Goal
Custom ~60×60mm flight controller (oversized bench board for hand assembly; 30.5mm M3 mount retained) around the STM32F405RGT6, running Betaflight via a custom target (`config.h`), driving the existing Flycolor Raptor BLS-04 4-in-1 ESC through its original 10-pin harness.

## Open items (blocking schematic)
1. ~~ESC harness pinout UNVERIFIED~~ **RESOLVED 2026-06-16** — manufacturer pinout diagram obtained; cross-checks against the old v1 candidate (same physical layout, opposite numbering). See verified table below. Remaining: 30-sec continuity beep on VBAT + 2×GND to ESC XT60 pads to confirm pin-1 orientation isn't mirrored before first power-up.
2. Crystal load caps: confirm 22pF against the chosen crystal's CL spec (22pF fits CL≈12–14pF with ~2–3pF stray; CL=18pF would need ~30pF).

---

## Hardware Stack

### ESC — Flycolor Raptor BLS-04 4-in-1 (owned)
- BLHeli_S, EFM8BB21-family ESC MCU (per Flycolor S-Tower manual) → **Bluejay-flashable** for bidirectional DSHOT / RPM filtering (verify layout in ESC-Configurator first)
- 3–6S LiPo, 60–65A continuous / 70A burst, 500k eRPM limit
- DSHOT150/300/600, OneShot125/42, Multishot
- **No BEC** — exposes raw VBAT only
- **No serial telemetry** (BLHeli_S limitation; RPM comes via bidir DSHOT after Bluejay)
- 30.5×30.5mm M3 mounting (tower stack — matches FC hole pattern)
- FC interface: 10-pin JST SH1.0

### ESC connector — VERIFIED pinout (manufacturer diagram, 2026-06-16)
From the BLS-04 pinout diagram. Cross-checks against the v1 candidate (identical physical layout — GND/GND/VBAT cluster at one end, CRT/TX at the other, 4 motor signals in the middle — just numbered from the opposite end). Listed in diagram order (one end → other).

| Signal | FC destination | Protection |
|----|----|----|
| TX (ESC telemetry TX) | spare UART RX pad (USART6 RX = PC7) or NC | none — **non-functional on BLHeli_S** (RPM via bidir DSHOT after Bluejay) |
| CRT (current sense, analog) | PC2 (ADC123_IN12) | **1kΩ series + 3.3V Zener clamp (required)** |
| S1 (motor 1) | PB0 | — |
| S2 (motor 2) | PB1 | — |
| S3 (motor 3) | PA3 | — |
| S4 (motor 4) | PA2 | — |
| NC | — | — |
| VBAT (raw pack +, up to 25.2V/6S) | PC1 (ADC123_IN11) **+ TPS5430 buck VIN** | **100k/10k divider + 100nF (sense); also feeds onboard buck input via 50V caps (required)** |
| GND | Ground plane | — |
| GND | Ground plane | — |

**Pre-power continuity check (battery disconnected):** beep from the cable's VBAT and both GND pins to the ESC XT60 pads to confirm pin-1 orientation matches the FC footprint (1:1 SH1.0 cable mirrors pin order; a mirrored connector puts up to 25.2V on a 3.3V GPIO). Motor order (S1–S4) needs no verification — remapped in Betaflight.

### Power
```
LiPo (3–6S, ≤25.2V) → BLS-04/Trinx ESC → raw VBAT on 10-pin harness
   VBAT ─┬─→ sense divider 100k/10k → PC1 (ADC)
         └─→ TPS5430DDAR buck (VBAT→5V, 3A) ─┬─ 5V rail
USB-C VBUS → Schottky (SS34/B5819W) ─────────┘
5V rail → AP2112K-3.3 (600mA) → 3.3V: MCU, flash, LED, logic, BMI270 VDDIO (pin 5)
5V rail → TLV733P-3.3 (LCSC C134139) → [JP10] → 3.3V_IMU: BMI270 VDD (pin 8) only — dedicated quiet rail
5V rail → receiver header (FS-iA6B, 5V), active buzzer
```
- **Onboard buck (NEW 2026-06-23): TPS5430DDAR (LCSC C9864), 5.5–36V in → 5V/3A**, fed from the ESC-harness VBAT. Replaces the external Matek MBEC6S (removed) — the BLS-04 / Trinx G20 ESCs have **no BEC**, so the FC must make its own 5V like a normal stack FC. Support parts (locked to TI datasheet values): **22µH ≥3A shielded inductor (CKCS6028, C354622)**, **SS34 catch diode (PH→GND)** (= datasheet B340A), 10nF BOOT cap, feedback **R1=10k / R2=3.24k** (Vref 1.221V → 5.0V), input **2×10µF 50V X7R (GRM32ER71H106KA12L, C77102)**, output **220µF aluminum-polymer (~20–40mΩ ESR) — NOT pure ceramic** (the TPS5430 is internally compensated for some output-cap ESR; all-ceramic output can oscillate).
- **6S input caps must be ≥50V rated** (25.2V rail). Keep the buck switching loop (input cap → IC → inductor → diode) physically tight and the PH/switch node **away from the IMU and the VBAT/current ADC traces**; the TLV733P then filters residual switching ripple off the gyro rail.
- Schottky ORing lets USB power the MCU + receiver on the bench; the onboard buck dominates in flight. No backfeed into USB.
- AP2112K: 1µF in, 1µF out (ceramic X7R or X5R per datasheet Note 4). EN tied to 5V rail — always-on (VIH max = 6.0V, so 5V is safe). TLV733P: 1µF in/out + 100nF at IMU pins.

---

## MCU — STM32F405RGT6**TR**, **LQFP-64** (10×10mm, 0.5mm pitch; order LCSC C15742 — tape-and-reel/cut-tape, 600 in stock, buy-1)
Required support circuitry:
- 8MHz crystal (HSE) + 2× load caps (size per CL — open item 2)
- Decoupling: 100nF per VDD pin + one 4.7µF bulk; 1µF+10nF on VDDA
- **VCAP_1 (pin 31) and VCAP_2 (pin 47): 2.2µF X5R/X7R each, placed at the pin** (core regulator stability — mandatory)
- MCU VBAT pin → 3.3V + 100nF
- BOOT0: 10k pull-down + button to 3.3V (DFU entry)
- **BOOT1/PB2: 10k pull-down** (BOOT0=1 requires BOOT1=0 for system-memory DFU; floating = unreliable boot target)
- NRST: button to GND + 100nF
- USB FS on PA11/PA12: **no series resistors needed** (AN4879 — internal impedance). Optional USBLC6-2SC6 ESD array.
- USB-C: 5.1k on CC1 and CC2 to GND
- VBUS sense: 10k/10k divider from VBUS to PC0 (optional; Betaflight `USB_DETECT_PIN`)
- **SWD header: 3.3V, SWDIO (PA13), SWCLK (PA14), NRST, GND** — keep PA13/PA14 unassigned

## Pin Assignment

| Function | Pin | Notes |
|----|----|----|
| Motor pads A–D | PB0, PB1, PA3, PA2 | TIM3_CH3, TIM3_CH4, TIM2_CH4, TIM2_CH3. Map to S1–S4 in config.h after harness verification — copy OMNIBUSF4 `TIMER_PIN_MAP` rows verbatim (known-good DSHOT DMA) |
| IMU SPI1 | PA5/PA6/PA7 | SCK/MISO/MOSI |
| IMU CS | PC4 | **10k pull-up to 3.3V_IMU** (no floating CS during boot/DFU) |
| IMU INT | PC3 | EXTI3, keep trace short |
| Flash SPI2 | PB13/PB14/PB15 | SCK/MISO/MOSI |
| Flash CS | PB12 | |
| USB | PA11 (D−), PA12 (D+) | length-matched pair |
| VBUS sense | PC0 | optional |
| UART1 (receiver) | PA9 TX, PA10 RX | **FlySky FS-iA6B → i-BUS on RX (PA10, 5V-tolerant)** — non-inverted, no inverter; Betaflight provider IBUS. TX = optional i-BUS telemetry |
| UART3 (spare pads) | PB10 TX, PB11 RX | future GPS/MSP; **not** ESC telemetry (none on BLHeli_S) |
| USART6 (spare pads) | PC6 TX, PC7 RX | costs nothing now |
| I2C1 (spare pads) | PB6 SCL, PB7 SDA | future baro/mag |
| VBAT ADC | PC1 | ADC123_IN11 |
| Current ADC | PC2 | ADC123_IN12 |
| Buzzer | PC5 | GPIO → 2N7002 low-side |
| Status LED | PB8 | PC13 forbidden (power-switch domain, ~3mA, DS8626) |
| SWD | PA13/PA14 | header only |

## Component List

**MCU support:** STM32F405RGT6 (LQFP-64) · 8MHz crystal + load caps · decoupling per above · **2× 2.2µF VCAP** · 2× 10k (BOOT0, PB2) · BOOT0/NRST tact switches · USB-C receptacle + 2× 5.1k · optional USBLC6-2SC6

**Power:** **TPS5430DDAR buck (ESOP-8, C9864) — VBAT→5V/3A** + 22µH inductor (C354622) + SS34 catch diode + 10nF boot + 10k/3.24k FB + 2×10µF 50V Cin (C77102) + 220µF polymer Cout · AP2112K-3.3 (SOT-23-5) · **TLV733P-3.3 (SOT-23-5, C134139)** · SS34/B5819W Schottky (USB OR) · caps per power section · ~~5V/GND input pads (MBEC6S)~~ **removed — FC powered from ESC VBAT via onboard buck**

**IMU (CURRENT — updated 2026-07-30):** **Bosch BMI270** (U7, LCSC C2836813, ~$0.82–1.79, buy-1 in stock) on footprint `drone_lib:LGA-14_L3.0-W2.5-P0.50-BR` — **VDD (pin 8) on dedicated 3.3V_IMU with 100nF; VDDIO (pin 5) on main 3.3V with 100nF** · ASDx (2) + ASCx (3) → **VDDIO** (must NOT be grounded) · INT2 (9), OCSB (10), OSDO (11) → **unconnected** · INT1 (4) → PC3/EXTI3 · CSB (12) → PC4 with 10k pull-up to +3V3 · SCx (13) → PA5, SDx (14) → PA7/MOSI, SDO (1) → PA6/MISO · board center. Pad-by-pad table in `VERIFIED_PINOUT.md` § IMU.
- **`+3V3_IMU` reaches VDD through solder jumper JP10 (`SolderJumper_2_Open`) — bridge it, or the gyro is unpowered.**
- **Betaflight define = `BMI270`** (`USE_GYRO_SPI_BMI270` / `USE_ACC_SPI_BMI270`). PID loop ceiling **3.2 kHz** (not 8 kHz), SPI clock ceiling **10 MHz** (not 24 MHz), ~8 KB init blob uploaded at boot, chip boots in I2C and needs a CSB rising edge to enter SPI. `GYRO_1_ALIGN` must be re-derived — the 42605 guess does not carry over.
- **Known tradeoff (this was the original reason for rejecting it):** the BMI270 ships uncalibrated, which Betaflight cites when discouraging it for new designs — a few percent attitude error. Irrelevant in Acro freestyle, visible in Angle/Horizon and level trim. Accepted because the alternative was not building the board.

> **SUPERSEDED (kept for history — 2026-06-23 decision, reversed 2026-07-30):**
> ~~ICM-42605 (LCSC C2655099, ~$9.38) default populate; VDD 0.1µF+2.2µF, VDDIO 10nF; RESV pin 7→GND mandatory, RESV 2/3/10/11 + INT2/FSYNC→GND.~~
> ~~Footprint is the TDK 426xx LGA-14 shared with ICM-42688-P (C1850418), pin-compatible — populate whichever is in stock. BMI270 evaluated and rejected: BF discourages it for new designs (uncalibrated gyro); not worth leaving the 426xx footprint.~~
> ~~Gyro define = `ICM42605` or `ICM42688P` depending on which is fitted.~~
> Reversed because the whole 426xx family became reel-only (MOQ 1000+) / OOS at qty 1 across LCSC, DigiKey and Mouser. There is **no** pin-compatible alternate for the current footprint.

**Blackbox (CURRENT — updated 2026-07-30):** **GigaDevice GD25Q16E** (LCSC C2904431, SOIC-8 208mil, SPI2) + 100nF — **16 Mbit = 2 MB, not 16 MB.** Wrong part ordered vs the 128 Mbit spec; kept. Betaflight needs no code change (`USE_FLASH_W25Q128FV` only gates the generic `m25p16` driver, which detects by JEDEC ID; our chip is `{ 0xC84015, 104, 50, 32, 256 }` = 2,097,152 B). Configurator reporting 2 MB is correct. **Set `blackbox_sample_rate = 1/4`** at bring-up → 800 Hz logging, ~87 s per erase; at 1/1 you get ~22 s. Upgrade path: GD25Q128E (C2758105) or BY25Q128ES (C22471255), same JEDEC table, identical pinout, hot-air swap.
> ~~**Blackbox:** W25Q128JVSIQ (16MB SOIC-8, SPI2) + 100nF~~ — superseded (MOQ 12–14 @ ~$25–30), then superseded again by the ordering error above.

**Connectors:** JST SH1.0 10-pin (ESC) — SM10B-SRSS-TB, **LCSC C160409** (side-entry SMD; confirm vs top-entry against stack routing) · USB-C receptacle — TYPE-C-31-M-12, **LCSC C165948** (JLC-basic) · **4-pin receiver header: 5V, GND, TX, RX** (generic 2.54mm, KiCad stock) · SWD header (generic 2.54mm, KiCad stock) · spare pads: UART3, USART6, I2C1 (J5 external 5V-in pads removed — FC now powered from ESC VBAT via onboard buck)

**Misc:** **active** 5V magnetic buzzer — SUN-12095-5VPA7.6, **LCSC C360615** (active, built-in driving circuit, through-hole 12mm). **Hand-soldered → mark DNP in JLC BOM; place footprint + BZ+/BZ− pads only.** Betaflight beeper is on/off GPIO — passive buzzers only click. + 2N7002 + 1N4148 flyback · status LED + 330Ω on PB8 · VBAT divider 100k/10k + 100nF · current input 1k series + 3.3V Zener

### Locked LCSC part numbers (import via easyeda2kicad → `D:\Drone\drone_PCB\libs\drone_lib`)
| Part | LCSC | Notes |
|----|----|----|
| STM32F405RGT6**TR** | C15742 | tape-and-reel/cut-tape, 600 stock, buy-1; KiCad stock symbol `STM32F405RGTx` OK |
| **BMI270 (IMU)** | **C2836813** | **CURRENT PART (2026-07-30).** Bosch, buy-1 in stock. Footprint `LGA-14_L3.0-W2.5-P0.50-BR`. No pin-compatible alternate. |
| ~~ICM-42605 (IMU)~~ | ~~C2655099~~ | ~~default populate; shared 426xx footprint w/ ICM-42688-P (C1850418)~~ — **SUPERSEDED**, 426xx reel-only/OOS at qty 1 |
| **GD25Q16E (flash)** | **C2904431** | **AS-FITTED. 2 MB, not 16 MB — wrong part ordered, kept.** BF-supported via m25p16 JEDEC table, no code change. Set `blackbox_sample_rate = 1/4`. |
| ~~W25Q128JVSIQ (flash)~~ | ~~C97521~~ | superseded — MOQ 12–14 (~$25–30) |
| BY25Q128ES / GD25Q128E | C22471255 / C2758105 | not fitted — documented 16 MB upgrade path, identical SOIC-8 208mil pinout |
| TLV733P-3.3 | C134139 | IMU rail LDO |
| AP2112K-3.3 | C51118 | main 3.3V LDO |
| TPS5430DDAR (buck) | C9864 | onboard VBAT→5V/3A, ESOP-8; needs L1 + Cin + Cout + diode + FB below |
| 22µH inductor (buck L1) | C354622 | CKCS6028-22µH/M, 6028 shielded, ~3A; buck switch inductor |
| 10µF 50V X7R (buck Cin) | C77102 | Murata GRM32ER71H106KA12L, 1210; ×2 on buck VIN |
| 220µF polymer (buck Cout) | (assign at BOM) | aluminum-polymer ~20–40mΩ ESR; **not ceramic** (loop stability) |
| 3.24k 1% (buck FB R2) | (assign at BOM) | 0603; sets 5.0V with R1=10k |
| USB-C receptacle | C165948 | TYPE-C-31-M-12 |
| JST SH1.0 10-pin | C160409 | SM10B-SRSS-TB, ESC |
| USBLC6-2SC6 | C7519 | optional USB ESD |
| Buzzer | C360615 | **DNP / hand-solder** |
| Passives, headers | — | KiCad stock symbols; assign LCSC # at JLC BOM stage |

## Board
- **~60×60mm outline**, holes 30.5×30.5mm M3 (matches BLS-04 tower — board overhangs the stack; fine for a bench build, and the extra area eases hand assembly)
- **Single-sided assembly: ALL SMD on top (L1)** — one hotplate reflow pass, no flip. Do not place parts on the bottom.
- 4-layer: L1 signal/components · L2 solid GND (unbroken under IMU) · L3 power pours (3.3V / 3.3V_IMU / 5V) · L4 signal
- Layout priorities: IMU dead-center over solid ground, TLV733P adjacent; VCAP + decoupling at pins; crystal loop tight, away from USB; USB pair matched; motor traces away from IMU. Size to the hotplate's even-heat zone (~100mm plate)
- **Fab + assembly: order BARE 4-layer boards + frameless stencil from JLCPCB; self-populate** with leaded (Sn63/Pb37 T4) paste + stencil + ~100mm hotplate. Keep a hot-air station for the LGA IMU and bridge/rework. (No PCBA — F405 + all SMD reflowed by hand.) Bare 4-layer + stencil ≈ $20–40 / 5 boards.

## Build Order
1. **Verify ESC harness pinout** (protocol above) → update table → only then start KiCad
2. Power: **onboard TPS5430 buck (VBAT→5V)** + USB ORing → AP2112K + TLV733P rails
3. MCU: crystal, decoupling, **VCAP**, BOOT0 + **PB2**, NRST, VBAT pin
4. USB-C + CC resistors (+ ESD optional), VBUS divider
5. ESC connector per verified table; ADC protection (divider+cap, 1k+Zener)
6. IMU on SPI1 + CS pull-up + INT; flash on SPI2
7. Receiver header (5V!), spare UART/I2C pads, SWD header
8. Buzzer (active) + LED (PB8)
9. ERC → layout (single-sided, all parts on top) → DRC → JLCPCB DFM → **order bare boards + frameless stencil** → self-reflow (stencil + leaded paste + hotplate; hot-air for IMU/rework)
10. Bring-up (props off, ESC disconnected): rail smoke test → SWD/DFU connect → flash custom target (`make configs && make ETHANF405` — skeleton in audit §7) → Configurator sensor/flash check → connect verified harness → motor test no props → calibrate vbat scale (~110) and current scale (bench sweep, unknown V/A) → optional Bluejay flash for RPM filtering

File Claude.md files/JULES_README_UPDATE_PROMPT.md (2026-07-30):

# Prompt for Google Jules — Update README.md

Copy everything below the line into Jules.

---

## Task

Update `README.md` in this repository. It has gone stale: several key components changed during the design, and the project has moved from "schematic complete" to "boards ordered from JLCPCB." Rewrite the affected sections using the facts below.

**Preserve the existing structure, headings, and first-person engineering-narrative voice.** This is a portfolio/resume repo, so the writing should stay technical and specific — explain *why* decisions were made, not just *what* the parts are. Do not invent specifications that aren't listed here. Do not change sections that aren't mentioned.

## 1. Add a board render at the top

Immediately under the `# Custom Drone Flight Controller PCB` heading and before `## Overview`, insert:

```markdown
![Flight controller PCB, top view](images/pcb-top.png)
```

The image file will be added separately — just place the reference.

## 2. IMU changed: ICM-42605 → Bosch BMI270

**What changed:** The design now uses the **Bosch BMI270** (LCSC C2836813) instead of the ICM-42605.

**Why:** The entire TDK InvenSense 426xx family (ICM-42605, ICM-42688-P, IIM-42652) became unobtainable in single quantities — reel-only minimum orders of 1000+ at LCSC, and out of stock or backordered at DigiKey and Mouser. The BMI270 is stocked at quantity 1 and is a current-generation gyro used on the majority of new commercial flight controllers, with mature Betaflight support.

**Engineering impact worth writing up:** The BMI270 is *not* a drop-in. Although it shares the same 2.5×3mm 14-pin LGA package outline, its pinout is completely different, which required a new footprint and re-routing every IMU net. Its decoupling requirement is also simpler (100nF at VDD and 100nF at VDDIO, versus the 2.2µF/0.1µF/10nF arrangement the 426xx wanted).

**The narrative angle to emphasize:** The existing dual-LDO architecture absorbed this mid-design part swap without any change to the power design — VDD still sits on the dedicated quiet TLV733P rail and VDDIO still sits on the main AP2112K logic rail. This is a concrete payoff of the isolation decision described in "Why This Approach." Rewrite that first bullet so it reflects the BMI270 and makes this point: designing for rail isolation up front meant a forced sourcing change cost only a footprint and a re-route, not a power redesign.

**Also update:** Betaflight gyro define is now `BMI270`.

## 3. Blackbox flash: W25Q128JVSIQ → BY25Q128ESSIG (spec) → **GD25Q16E, 2 MB (actually fitted)**

**What changed:** Blackbox flash as **actually ordered and fitted** is the
**GigaDevice GD25Q16E** (LCSC C2904431) — **16 Mbit = 2 MB**, not the 16 MB the
BOM specified.

**Why (two steps):** The Winbond W25Q128JVSIQ hit a minimum order quantity of
12–14 units (~$25–30), so the BOM moved to the BOYAMICRO BY25Q128ES (C22471255,
16 MB, ~$0.36, SOIC-8 208-mil drop-in, explicitly named in Betaflight's supported
flash list). **Then the wrong part was actually ordered** — a 16 Mbit GD25Q16E
instead of a 128 Mbit chip. Caught 2026-07-30 while reconciling the BOM files.

**Decision: keeping it.** It works with no firmware change, because
`USE_FLASH_W25Q128FV` is not a chip selector — it only gates Betaflight's generic
`m25p16` driver, which identifies chips by JEDEC ID at runtime. The GD25Q16E is in
that driver's table (`{ 0xC84015, 104, 50, 32, 256 }` = 2,097,152 bytes).

**Engineering angle worth writing up honestly:** the cost is log *duration*, not
function — roughly 22 s at a 3.2 kHz log rate, ~87 s at `blackbox_sample_rate = 1/4`
(800 Hz). Since 800 Hz still resolves everything below 400 Hz, where the motor and
frame noise peaks that filter tuning depends on actually sit, and tuning runs are
30–60 s anyway, the practical loss is only the ability to log a whole pack. The
recovery cost is also near zero: every candidate part shares the SOIC-8 208-mil
footprint, so upgrading to GD25Q128E (C2758105) or BY25Q128ES (C22471255) is a
hot-air swap with no layout or firmware change. Worth presenting as a sourcing
mistake caught by cross-checking three BOM files against the firmware, and
mitigated in configuration rather than copper.

**Do not claim the board has 16 MB of blackbox storage.**

## 4. Buck regulator changed: TPS5430DDAR → TPS5450DDAR

**What changed:** The onboard buck is now the **TPS5450DDAR** (LCSC C114425).

**Why:** The TPS5430DDAR (C9864) went out of stock. The TPS5450 is a pin-for-pin drop-in — same ESOP-8/DDA package, same pinout, same 1.221V feedback reference (so the existing 10k/3.24k divider still yields 5.0V), same 5.5–36V input range — with a 5A rating instead of 3A. All buck support passives are unchanged.

## 5. Battery changed: 3–6S → 4S

**What changed:** The design target is now a **4S LiPo (14.8V nominal, 16.8V full charge)**, not 3–6S up to 25.2V.

**Consequences to reflect:** the buck output inductor is 15µH (was 22µH), and input capacitor voltage ratings could relax from ≥50V to ≥25V (50V parts are still used for transient margin).

## 6. Update "Current Status"

Replace the entire "Current Status (Work in Progress)" section. The new status:

**Boards ordered from JLCPCB on 2026-07-19 — awaiting delivery (~2 weeks).**

- Schematic and PCB layout complete; **ERC and DRC both clean**.
- 4-layer stackup: L1 signal/components, L2 solid ground, L3 power pours, L4 signal. All SMD on the top layer for a single hotplate reflow pass.
- Ordered as bare 4-layer boards (ENIG finish, chosen for reliable soldering of the LGA gyro and fine-pitch parts) plus a frameless top-side stencil, quantity 5.
- Next step is assembly and staged bring-up once boards arrive.

## 7. Add a new section: "Design for Bring-Up"

Add a new section (place it after "Interfaces"). This is a differentiating detail for a portfolio repo — the board was deliberately designed to be debuggable:

- **Staged power isolation:** normally-open solder jumpers split the power tree at four points — buck 5V output to the rest of the 5V rail, 5V to each of the two LDOs, and the quiet 3.3V rail to the IMU. Each stage is brought up and verified on a current-limited bench supply before the next jumper is closed, so a fault in one stage cannot propagate downstream.
- **Test points** on every rail (VBAT, 5V, 3.3V, 3.3V_IMU) plus multiple grounds, the buck switch node and feedback node for scoping, and both ADC sense lines for calibration. Dedicated ground loops near the buck and IMU for short scope-ground connections.
- **Spare GPIO broken out:** all 16 unused STM32 pins are routed to a labelled header, including timer-capable pins for motor reassignment, a spare UART, spare ADC channels, and SWO — insurance against a pin-level mistake requiring a full respin.

## 8. Optional — add a "Notable Design Details" section

If it fits naturally, add a short section covering:

- **Motor output DMA conflict:** motor 4 was moved from PB7 to PB5 (TIM3_CH2) to clear a DMA1 Stream 3 collision with SPI2_RX (the blackbox flash). Final motor mapping is M1=PB0, M2=PB1, M3=PB6 (TIM4_CH1), M4=PB5 (TIM3_CH2), verified against RM0090's DMA request mapping table.
- **Buck output capacitor:** a Panasonic POSCAP 10TPB220M (220µF, 10V, 40mΩ ESR) — the exact part named in TI's datasheet worked example. A pure-ceramic output would have too little ESR and risks loop instability, since the TPS545x is internally compensated assuming some output-cap ESR.
- **ADC input protection:** the ESC current-sense line is clamped with a 1kΩ series resistor and a 3.3V zener to protect the STM32 ADC pin.

## 9. Update the "Build Instructions" section

Adjust step 1 to reflect that boards and stencil are already ordered, and fold the staged-jumper bring-up sequence into step 2.

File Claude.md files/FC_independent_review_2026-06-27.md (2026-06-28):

# Independent Design Review — STM32F405 Flight Controller
**Date:** 2026-06-27   **Scope:** schematic only (PCB layout not reviewed)

**Method:** Connectivity was extracted geometrically from the `.kicad_sch` s-expressions — each symbol's pin coordinates transformed by its instance rotation/mirror, then wires/junctions/labels/power-symbols unioned into real nets (not inferred from layout appearance). Pin functions were re-derived from the STM32F405 datasheet (DS8626) and RM0090 for the **LQFP-64** package; every IC was checked against its own datasheet. Quoted nets are the actual extracted nets.

**Transform caveat (important for trust):** a geometric parser can place a 2-pin part (diode, polarized cap) in either of two mirror orientations when both pads land on wires, which swaps *pin identity* (K↔A) without changing *which nodes* connect. I therefore re-verified every polarity-sensitive part (D2/D3/D4) with a transform **calibrated against a known multi-pin part (U5 TPS5430)**. Net connectivity (what connects to what) is reliable throughout; the diode polarities below are the calibrated results.

## VERDICT: ⛔ NO-GO for fabrication
Three fabrication-blocking errors (VDDA shorted to GND, VCAP_1 missing its capacitor, buck feedback resistor value) plus an unrouted receiver link. None are layout-fixable — they require schematic changes. Fix the Critical + M1 items, close KiCad and re-run ERC (the on-disk files are mid-save/truncated), then re-review.

---

## CRITICAL — will not work / damages parts

### C1. VDDA (pin 13) is shorted to GND
**File:** `MCU-STM32F405.kicad_sch` · **Pin/net:** `U4` pin 13 `VDDA` → net **GND**
**Evidence:** VDDA's only wire is (147.32,52.07)→(147.32,48.26)→(157.48,48.26), where a **junction** ties it to both the C18/C19 bottom-plate rail and a `power:GND` symbol at (157.48,50.8). The ferrite output FB1.2 feeds only C18.1/C19.1 (the cap **top** plates) — a dead node that never reaches VDDA. Confirmed with the calibrated transform (U4 is rot 0/no-mirror; VDD/VSS/SPI pins all land correctly) and by the GND symbol identity.
**Datasheet rule:** DS8626 power-supply scheme — *"VDDA and VSSA must be connected to VDD and VSS respectively"*; *"a maximum difference of 300 mV between VDD and VDDA."* Here VDD = 3.3 V, VDDA = 0 V → 3.3 V delta (~11× the limit). On LQFP-64 there is **no separate VREF+ pin** (VREF+ is bonded to VDDA internally), so this also kills the ADC reference.
**Consequence:** ADC (VBAT/current sense) dead; analog domain unpowered; the 3.3 V→0 V delta can forward-bias internal protection → possible latch-up/damage. Board will not run correctly.
**Fix:** Connect VDDA (pin 13) to the **ferrite-output node** (FB1.2 = C18.1 = C19.1). End state: `+3V3 → FB1 → VDDA`, with C18 (10 nF) and C19 (1 µF) from **VDDA to GND**. As drawn, the VDDA pin is tapped onto the cap-bottom/GND rail instead of the cap-top/ferrite rail.

### C2. VCAP_1 (pin 31) is floating — missing 2.2 µF core-regulator capacitor
**File:** `MCU-STM32F405.kicad_sch` · **Pin/net:** `U4` pin 31 `VCAP_1` → stub to (99.06,133.35), no component. Only VCAP_2 (pin 47) has its cap (C13, 2.2 µF → GND). VCAP_1 is not tied to VCAP_2.
**Datasheet rule:** DS8626 §5.3.2 / power-supply scheme — *"Two external ceramic capacitors should be connected on VCAP_1 & VCAP_2 pin,"* **2.2 µF** low-ESR each. LQFP-64 has two independent VCAP pins; each needs its own cap.
**Consequence:** The internal 1.2 V core regulator on the VCAP_1 domain is undecoupled → unstable core rail; the MCU may not start or may run erratically.
**Fix:** Add a 2.2 µF X7R from **VCAP_1 to GND**, placed at the pin (mirror C13).

### C3. Buck feedback resistor R8 is annotated "3.24" (reads as 3.24 Ω; must be 3.24 kΩ)
**File:** `buck-converter.kicad_sch` · **Net:** VSENSE divider R7 (10k, top) / R8 (bottom) into `U5` pin 4
**Rule:** TPS5430 Vref = **1.221 V**; TI's typical 5 V design (datasheet figure) is **R1 = 10 kΩ, R2 = 3.24 kΩ** → Vout = 1.221·(1 + 10k/3.24k) = 5.0 V. The `Value` field is the bare string **`3.24`**, which KiCad/BOM read as 3.24 Ω.
**Consequence (if built as drawn):** R7/R8 = 10000/3.24 ≈ 3086 → the regulator drives Vout toward battery voltage trying to reach 1.221 V on VSENSE → the "5 V" rail rises to ~VBAT → destroys both LDOs, USB, the ESD device, and everything downstream of 5 V.
**Fix:** Set R8 = **3.24 kΩ** explicitly in the symbol Value and BOM. (Likely just a missing "k", but it must be corrected before BOM export.)

---

## MAJOR — functional risk

### M1. Receiver / UART header (J3) is not connected to the MCU
**File:** `IO.kicad_sch` · **Nets:** `UARTx_RX` = `{J3.3}` only; `UARTx_TX` = `{J3.4}` only — neither label appears on any MCU pin (verified against the full MCU label set).
**Consequence:** No path for the FS-iA6B iBUS (or any RX protocol) into the MCU → no radio-control input. iBUS is non-inverted, so it only needs a direct USART RX — but that RX is unrouted. (May reflect a work-in-progress sheet, but it is a hard blocker for a flyable board.)
**Fix:** Wire `UARTx_RX`/`UARTx_TX` to a free USART — e.g. PA10/PA9 (USART1), PB11/PB10 (USART3), or PC7/PC6 (USART6). All are currently unused and RX-capable.

### M2. Blackbox-flash SPI2_RX DMA collides with motor-4 (TIM4_CH2) on DMA1 Stream 3
**Files:** `MCU-STM32F405.kicad_sch`, `Blackbox-flash.kicad_sch`, `IO.kicad_sch`
**Evidence + RM0090 Table 42:** The four motors map to PB0=TIM3_CH3 (DMA1 **S7**), PB1=TIM3_CH4 (**S2**), PB6=TIM4_CH1 (**S0**), PB7=TIM4_CH2 (**S3**). The blackbox flash is on SPI2: **SPI2_RX = DMA1 Stream 3**, SPI2_TX = DMA1 Stream 4. So **motor-4 DSHOT DMA (TIM4_CH2 → Stream 3) and SPI2_RX (Stream 3) are the same stream** — they cannot both run.
**Consequence:** A DMA conflict the firmware target must resolve. In practice blackbox *writes* use SPI2_TX (Stream 4, no conflict) and log *download* uses RX with motors disarmed, so it's often survivable — but it constrains the target and can break DMA-based flash reads while armed.
**Fix (optional but clean):** Drive motor 4 from **PB5 (TIM3_CH2 = DMA1 Stream 5)** instead of PB7 — conflict-free against SPI2 (S3/S4), SPI1 (DMA2) and the other three motors (S0/S2/S7). PB5 is currently free. This requires re-routing the CN1 motor-4 net and its label from TIM4_CH2 to TIM3_CH2.

### M3. IMU VDD / VDDIO rails are assigned backwards (defeats the quiet LDO)
**File:** `IMU-ICM42605-p.kicad_sch` · **Pins/nets:** `U6` pin 8 `VDD` → **+3V3** (main, shared/noisy); pin 5 `VDDIO` → **+3V3_IMU** (quiet TLV73333 LDO). Confirmed with the calibrated transform; decoupling follows the rails (C10 2.2 µF + C11 0.1 µF on VDD/main per the ICM-42605 datasheet typical circuit; C9 10 nF on VDDIO/quiet).
**Why it's wrong:** VDD powers the MEMS + analog front-end (the actual sensing); VDDIO only sets digital-I/O levels. The dedicated TLV73333 exists to give the gyro a clean supply, but only VDDIO sits on it while VDD shares the main rail with the MCU and flash. The clean LDO is wasted on the I/O pin.
**Consequence:** Gyro analog supply sees main-rail noise → worse noise floor / more filtering needed.
**Fix:** Power **VDD (pin 8) + C10 + C11 from +3V3_IMU**. Put VDDIO on +3V3_IMU as well (simplest — the 300 mA LDO trivially carries the <10 mA gyro) or leave VDDIO on main 3V3.

### M4. No VBAT voltage-sense divider to any ADC pin
**Files:** `IO.kicad_sch` / `buck-converter.kicad_sch` · **Net:** `+BATT` members = `{C5.1, CN1.8, U5.7}` — battery voltage reaches only the buck input. Current sense exists (`Current_meter` → PC1 = ADC123_IN11 ✓); battery-voltage sense does not.
**Consequence:** Betaflight cannot measure pack voltage on the FC (no VBAT telemetry/alarms/sag compensation).
**Fix:** Add a divider from `+BATT` to a free ADC pin (PC0/ADC123_IN10, PC2/IN12, or PA4/ADC12_IN4), scaled for **16.8 V (4S)** — e.g. ~10k/1k (≈11:1) keeps the ADC node ≤1.5 V — plus a 100 nF filter and a series/clamp consideration. (Depends on C1 — the ADC reference is dead until VDDA is fixed.)

### M5. Battery-rail capacitor voltage ratings unspecified — must be ≥25 V for 4S
**File:** `buck-converter.kicad_sch` · **Parts:** C5 (10 µF on `+BATT`) and any other `+BATT`-side ceramic. `Value` fields carry no voltage; passives are not in `libs/lcsc.txt`.
**Rule:** 4S full charge = **16.8 V** (transients higher). A 16 V-rated cap is **under-rated** at 16.8 V — a classic 4S trap. The original 6S intent *may* mean parts are already ≥35 V (safe), but confirm.
**Fix:** Specify `+BATT` ceramics at **≥25 V** (≥35 V keeps 6S headroom). C8 (220 µF) on the 5 V node needs ≥10 V. The TPS5430 (5.5–36 V in) and D2 (SS34, 40 V) are fine for both 4S and 6S.

### M6. ESC connector CN1 pin-1 keying must be verified on the PCB (16.8 V-onto-GPIO risk)
**File:** `IO.kicad_sch` (schematic mapping is correct, see below). This is a **layout/footprint** check the schematic can't settle.
**Risk:** `+BATT` (16.8 V) is on CN1 pin 8. If the SM10B-SRSS-TB footprint/keying is mirrored vs the Flycolor harness, a 180° reversal lands harness VBAT (pin 8) onto CN1 pin 3 = **TIM3_CH3 = PB0**, a 3.3 V GPIO → instant MCU death.
**Fix:** On the PCB, confirm CN1 pad-1 (silk + connector key) maps to harness pin 1 (TX) so VBAT lands on pad 8. Verify against the harness before first powered connection.

---

## MINOR — optimization / housekeeping
- **VDD decoupling count:** only 3×100 nF (C25–C27) + 1×4.7 µF (C28) for four VDD pins (19/32/48/64). DS8626 wants one 100 nF per VDD pin + the bulk; add a 4th 100 nF and ideally a 100 nF on VBAT (pin 1). *File: `MCU-STM32F405.kicad_sch`.*
- **ESC telemetry unused:** `CN1.1` (ESC TX) is unconnected — no ESC telemetry. Acceptable (bidirectional DSHOT still gives RPM); wire to a spare UART RX if wanted.
- **ADC vs gyro DMA:** ADC1 (DMA2 Str0/4) and SPI1-RX gyro (DMA2 Str0/2) both live on DMA2 — resolvable in firmware (pick non-overlapping streams), no board change needed. Worth noting for the custom target.
- **USB VBUS sense:** PA9/OTG_FS_VBUS unconnected — fine for a bus/self-powered F405 in Betaflight.
- **Flash exposed pad:** `U7` pin 9 (EP) → GND, but W25Q128JVSIQ (C97521) is SOIC-8 with no thermal pad — harmless; confirm the footprint so ERC doesn't flag a phantom pad.
- **TPS5430 ENA floating:** `U5` pin 5 (ENA) floats = enabled per datasheet (*"Float the pin to enable"*) — works; an optional VIN-referenced UVLO divider gives defined turn-on/brown-out.

---

## Verified CORRECT (checked against datasheets / calibrated geometry — no action)
- **VDDA filter parts present** (ferrite FB1 600 Ω + 10 nF + 1 µF) — only the VDDA pin connection is wrong (C1).
- **HSE crystal:** Y1 ↔ PH0(OSC_IN, pin5)/PH1(OSC_OUT, pin6) with C21/C22 (22 pF) to GND — correctly wired.
- **Reset/boot:** NRST = 100 nF (C20) + button to GND ✓; BOOT0 = 10k pulldown (R4) + button to +3V3 for DFU ✓; BOOT1/PB2 = 10k pulldown (R9) ✓.
- **Buck topology:** catch diode **D2 correctly oriented** (cathode→PH switch node, anode→GND — calibrated-transform verified); bootstrap C7 (0.01 µF) BOOT→PH per datasheet; L2 15 µH; 10 µF in / 220 µF out matches TI's 5 V reference design.
- **5 V diode-OR correctly oriented:** D3 (anode→+5V_Buck, cathode→+5V) and D4 (anode→+5V_USB, cathode→+5V) — Schottky OR into +5V; LDO inputs ≈4.6–4.9 V, within AP2112K / TLV73333 limits.
- **USB 2.0 FS:** D− = PA11 (pin 44), D+ = PA12 (pin 45) — no swap, no stray series R (F405 has internal series R). A6+B6 (D+) and A7+B7 (D−) tied for both C orientations. USBLC6-2SC6 in series, connector-side ESD; VBUS on pin 5; CC1/CC2 each 5.1 kΩ to GND (correct UFP pulldowns).
- **SPI bus separation:** gyro on **SPI1** (PA5/PA6/PA7 = AF5, soft CS = PC4), flash on **SPI2** (PB13/PB14/PB15 = AF5, soft CS = PB12) — separate peripherals, good practice. AFs confirmed in DS8626 Table 9.
- **Flash:** /CS (R10), /WP (R11), /HOLD (R12) all 10k pull-ups to +3V3; decoupled (C23 100 nF); EP→GND.
- **IMU strap/reserved pins (ICM-42605 datasheet Table):** pin 7 RESV→GND (required ✓), pins 2/3/10/11 RESV→GND (allowed ✓), pin 9 INT2/FSYNC→GND (correct for unused FSYNC ✓), INT1→PC3/EXTI3 ✓. Custom symbol pin-numbering matches the datasheet.
- **ESC connector CN1 mapping (vs Flycolor harness TX, CRT, S1–S4, NC, VBAT, GND, GND):** pin-for-pin correct — CRT→Current_meter→PC1; S1→TIM3_CH3/PB0; S2→TIM3_CH4/PB1; S3→TIM4_CH1/PB6; S4→TIM4_CH2/PB7; VBAT→+BATT; GND×2. **All four motors are connected.** (See M2 for the DMA-stream caveat on motor 4, and M6 for the keying check.)

---

## Ordered must-fix list (before re-spin / fab)
1. **C1 — VDDA short:** reconnect VDDA (pin 13) to the FB1 output node; C18/C19 from VDDA→GND. *(damages part / no ADC)*
2. **C2 — VCAP_1:** add 2.2 µF VCAP_1→GND. *(may not boot)*
3. **C3 — R8 value:** set to **3.24 kΩ** (not 3.24 Ω). *(5 V overvoltage)*
4. **M1 — RX link:** wire J3 `UARTx_RX/TX` to a free USART. *(no control input)*
5. **M3 — IMU rails:** move VDD (pin 8) + C10/C11 to **+3V3_IMU**. *(gyro noise)*
6. **M4 — VBAT sense:** add a 4S-scaled divider to a free ADC pin. *(no battery telemetry)*
7. **M5 — cap ratings:** specify +BATT-side caps ≥25 V. *(4S margin)*
8. **M2 — motor-4 DMA:** prefer PB5/TIM3_CH2 for motor 4 to clear the SPI2_RX/Stream-3 clash. *(firmware DMA conflict)*
9. **M6 — CN1 keying:** verify pad-1 orientation on the PCB. *(16.8 V onto PB0 if mirrored)*
10. Close KiCad (on-disk `MCU-` and `LDOs` sheets are mid-save/truncated), confirm a clean save, **run ERC** — it will independently flag C1, C2 and M1 as power-input / unconnected-pin errors — then re-review.

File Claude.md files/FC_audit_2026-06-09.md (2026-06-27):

# Betaflight F405 FC — Project Audit (2026-06-09)

**Scope:** Betaflight/STM32 path only. Audited against `drone_fc_project_context.md` (v1 on disk), prior-session corrections (LQFP-64, TLV733P, PB8 LED, SWD header), and your answers today: ESC = Flycolor Raptor BLS-04, no video system (bench/resume build).

**Verdict: Proceed with changes.** The architecture is sound and the MCU choice is right. But the schematic must not start from the v1 doc on disk — it contains two components that would brick the board (missing VCAP caps, missing BOOT1 strap), an unverified ESC pinout sourced from the wrong manual, and a telemetry feature your ESC firmware doesn't have.

---

## Critical

**C1. The ESC manual in the project is for a different ESC.**
The uploaded PDF (Flycolor doc 251400-1168-TX) is the **Trinx G20 4-in-1**: BLHeli_32, STM32G0, 20×20mm mount, pinout order TX/CRT/S1/S2/S3/S4/NC/VBAT/GND/GND. Your ESC is the **Raptor BLS-04** (tower product: BLHeli_S, 30.5×30.5mm, 60–65A/70A, 3–6S). No public text-searchable manual for the BLS-04 harness exists; the pinout table in the context doc matches the Trinx manual read **end-to-end reversed**, with pin 10 labeled NC where the Trinx puts telemetry TX. Provenance unknown = treat as unverified.
*Fix:* Before any schematic work, verify the physical unit: (1) photograph the ESC silkscreen at the 10-pin SH1.0 socket; (2) with battery disconnected, continuity-test each socket pin to the XT60 pads (finds VBAT and the two GNDs) and to each motor MOSFET cluster (finds S1–S4); (3) verify at the **FC end of the supplied cable** — a 1:1 SH1.0 cable mirrors pin order between the two boards. Lock the verified table into the v3 doc. Rationale (per project rule): a one-position error puts up to 25.2V on a 3.3V GPIO.

**C2. VCAP capacitors are missing from the design.**
The STM32F405's internal 1.2V core regulator requires a 2.2µF capacitor on **each** VCAP pin (VCAP_1 = pin 31, VCAP_2 = pin 47 on LQFP-64). The component list has decoupling for VDD/VDDA only — no VCAP caps anywhere. Without them the core supply is unstable and the MCU will not run reliably, if at all.
*Fix:* Add 2×2.2µF X5R/X7R (≥6.3V, 0603) placed immediately at the VCAP pins. Ref: STM32F405 datasheet (DS8626) §"Voltage regulator" and ST AN4488 hardware getting-started.

**C3. No BOOT1 (PB2) strap — DFU flashing will be unreliable.**
The plan has BOOT0 (10k pull-down + button) but never mentions PB2/BOOT1. Entering the ROM bootloader (your no-debugger flash path: BOOT0 button + USB DFU) requires BOOT0=1 **and** BOOT1=0. Floating PB2 means random boot target (system memory vs SRAM). Ref: ST AN2606 boot mode table.
*Fix:* 10k pull-down on PB2 (or tie direct to GND if you'll never use it as GPIO).

**C4. The context doc on disk is stale and would propagate fixed bugs.**
`drone_fc_project_context.md` still says LQFP-100 (the RGT6 is LQFP-64), single AP2112K (no TLV733P IMU LDO), LED on PC13 (3mA power-switch-domain pin; remapped to PB8 last session), and no SWD header. The corrected v2 was saved to a temporary session folder that no longer exists.
*Fix:* Regenerate a v3 context doc incorporating v2 fixes + this audit before opening KiCad. I can produce it on request.

---

## Significant

**S1. ESC telemetry header is a dead feature — BLHeli_S has no serial telemetry.**
The plan dedicates UART3 + a 3-pin header to "ESC telemetry (optional)". The BLS-04 runs BLHeli_S, which has no UART telemetry output (that's BLHeli_32/AM32/KISS territory). The wire would carry nothing.
*Fix:* Drop the dedicated telemetry header. Get RPM data the modern way instead: Flycolor's BLHeli_S towers use the **EFM8BB21F16** ESC MCU (per the Raptor S-Tower manual), which is supported by **Bluejay** — flash via ESC-Configurator to get bidirectional DSHOT → RPM filtering in Betaflight. Verify the BLS-04's exact layout in ESC-Configurator before flashing. Keep UART3 routed to pads as a spare (GPS/MSP later).

**S2. No 5V input or distribution on the board.**
The power chain names the external Matek MBEC6S, but the connector list has no 5V input pads, the receiver header has no 5V pin (an ELRS RX needs 5V, ~50–100mA), and there's no isolation between USB VBUS and the MBEC's 5V — on the bench with USB + battery connected, two regulated 5V sources fight each other.
*Fix:* Add 5V/GND input solder pads; add 5V to the receiver header; OR the two sources with a Schottky (e.g., SS34/B5819W) from VBUS into the 5V rail so USB can power MCU+RX for configuration, and the MBEC wins in flight. Onboard buck is a fine v2 upgrade but unnecessary now — the MBEC6S is owned and within spec (6–30V in, 1.5A).

**S3. Buzzer type: plan specifies a passive buzzer, Betaflight drives active ones.**
Betaflight's beeper is an on/off GPIO, not a tone generator — a passive transducer will click, not beep.
*Fix:* Spec a 5V **active** magnetic buzzer; keep the 2N7002 low-side switch + 1N4148 flyback. Set beeper polarity in the target config at bring-up.

**S4. Motor numbering must follow the verified harness, and timer/DMA config shouldn't be invented from scratch.**
Your four pins (PA2, PA3, PB0, PB1) are exactly the OMNIBUSF4 motor set — a decade-proven F405 target — but its mapping is Motor1=PB0, Motor2=PB1, Motor3=PA3, Motor4=PA2, the reverse of your table, and the true S1–S4 order is unknown until C1 is done.
*Fix:* Copy the OMNIBUSF4 `TIMER_PIN_MAP` rows for these pins verbatim (known-good DSHOT DMA assignments), then set `MOTORx_PIN` to match the verified harness. Reordering happens in config, not copper.

**S5. Current-sense scale is unknown.**
No datasheet states the BLS-04's CRT output V/A. The 1kΩ series resistor + Zener clamp plan is right (keep the Zener — 3.3V on a 65A sensor line is cheap insurance), but the Betaflight `current_meter_scale` must come from measurement.
*Fix:* Bench-calibrate post-build: measure CRT voltage at known currents (current clamp or charger-logged mAh comparison), set scale/offset in CLI.

---

## Minor

**M1. 22Ω USB series resistors are unnecessary on F405.** AN4879: the FS transceiver manages line impedance internally; no external series resistors needed. Harmless if kept; deleting saves two parts. Optional: USBLC6-2SC6 ESD array on D+/D−.
**M2. VBUS sense on PC0 is optional.** Betaflight supports it (`USB_DETECT_PIN`, cf. OMNIBUSF4 on PC5) but most F405 boards omit it. Keep or drop freely.
**M3. Crystal load caps: confirm against the chosen crystal's CL.** 2×22pF suits CL≈12–14pF with ~2–3pF stray. If you buy a CL=18pF part you'd need ~30pF. Check before ordering.
**M4. Add a 10k pull-up on IMU CS** (PC4→3.3V) so the ICM-42688-P can't see a floating CS during boot/DFU.
**M5. Spare pads cost nothing:** USART6 (PC6/PC7) and I2C1 (PB6/PB7, future baro/mag) broken out to pads keeps a 5th UART and sensor expansion open on a bench board that may grow.
**M6. MCU VBAT pin → 3.3V + 100nF** (not in the component list; required even if RTC unused).
**M7. Mounting confirmed good:** BLS-04 tower is 30.5×30.5 M3 — your hole pattern matches. (Had the ESC been the Trinx G20 of the uploaded manual, it would not have: 20×20.)

---

## The MCU question: keep the STM32F405RGT6

Checked alternatives (June 2026 data):

| MCU | LCSC price/stock | Betaflight status | Assessment |
|---|---|---|---|
| **STM32F405RGT6** | ~$2.12–2.61, deep stock, JLCPCB-assemblable (C15742) | Target platform present in master; wiki: "most common option" | **Keep** |
| AT32F435RGT7 | ~$2.70, only 362 in stock | Official since 4.5; pin-compatible with F405 | Fallback if F405 dries up; same footprint |
| STM32F722 | similar price, spottier stock | Supported | No meaningful gain for this project |
| STM32H743 | ~3–5× price, LQFP-100 | Supported | Overkill; harder layout, no resume gain |
| STM32G473 | cheap | "Not as developed and established" (BF wiki) | Weak community base |

F405 deprecation risk is low: Betaflight moved to year-based releases (4.5.x → 2025.12 → 2026.6) and F405 remains a first-class platform with the largest reference-design base — which is the point of this project. The pin-compatible AT32F435 means your exact footprint has a second source. No chip change recommended.

---

## Cost & timeline (rough)

JLCPCB 4-layer 40×40, qty 5, 2 assembled: PCB ~$8–20, SMT setup ~$25–35, parts ~$12–18/board (F405 $2.6 + ICM-42688-P ~$5 + flash, LDOs, connectors, passives). **≈ $80–120 landed for first spin.** Budget one respin. Part-time pace: schematic 1–2 wk, layout 1–2 wk, fab+ship 1–2 wk, bring-up + target file 1–2 wk → **~6–9 weeks**.

---

## Completion roadmap

1. **Verify ESC harness** (C1 procedure) → lock pinout table.
2. **Regenerate context v3** folding in v2 fixes + C2/C3/S1–S5/M-items.
3. **Schematic in KiCad** in the doc's build order, with additions: VCAP caps, PB2 strap, 5V pads + ORing diode, RX-header 5V, active buzzer, spare-UART/I2C pads. Run ERC.
4. **Layout:** IMU dead-center on solid L2 ground, TLV733P close to IMU, crystal short loop, USB pair length-matched, VCAP/decoupling at pins, motor signals away from IMU. DRC against JLCPCB 4-layer rules.
5. **Order** (JLCPCB economic PCBA; check PCBWay only if F405/IMU reels go out of stock).
6. **Bring-up, props off, ESC disconnected first:** smoke-test 5V/3.3V rails → SWD connect (ST-Link, `STM32_Programmer` or probe via DFU: BOOT0 held, USB) → flash → Configurator sensor check → blackbox flash test → only then plug verified ESC harness, motors spin-tested without props.
7. **Custom target:** clone `betaflight/betaflight` + `betaflight/config`; create `configs/ETHANF405/config.h`; `make configs && make ETHANF405`. Skeleton:

```c
#define FC_TARGET_MCU     STM32F405
#define BOARD_NAME        ETHANF405
#define MANUFACTURER_ID   CUST   // local-build only; rules apply only for official submission

#define USE_GYRO
#define USE_GYRO_SPI_ICM42688P
#define USE_ACC
#define USE_ACC_SPI_ICM42688P
#define USE_FLASH
#define USE_FLASH_W25Q128FV        // driver covers the JV die

#define GYRO_1_SPI_INSTANCE SPI1
#define GYRO_1_CS_PIN       PC4
#define GYRO_1_EXTI_PIN     PC3
#define FLASH_SPI_INSTANCE  SPI2
#define FLASH_CS_PIN        PB12

// Motor pins: set 1..4 to the bench-verified S1..S4 after C1.
// TIMER_PIN_MAP rows for PB0/PB1/PA3/PA2: copy from OMNIBUSF4 config.h (known-good DSHOT DMA).

#define ADC_VBAT_PIN        PC1
#define ADC_CURR_PIN        PC2
#define BEEPER_PIN          PC5   // set/clear BEEPER_INVERTED per 2N7002 bring-up test
#define LED0_PIN            PB8
#define SYSTEM_HSE_MHZ      8
#define DEFAULT_BLACKBOX_DEVICE BLACKBOX_DEVICE_FLASH
#define DEFAULT_VOLTAGE_METER_SOURCE VOLTAGE_METER_ADC
#define DEFAULT_CURRENT_METER_SOURCE CURRENT_METER_ADC
```

8. **Calibrate** vbat scale (110 nominal for 100k/10k) and current scale (S5). Flash Bluejay on the ESC if RPM filtering is wanted.

---

## Sources

- Flycolor Trinx G20 manual (the uploaded PDF, doc 251400-1168-TX) — pinout, BLHeli_32, 20×20 mount
- [Raptor BLS-04 F4 Tower listing (rc-wing)](https://rc-wing.com/products/flycolor-raptor-bls-04-f4-tower-f4-flight-controller-65a-esc-3-6s-stack) — 30.5×30.5, 3–6S, 60–65A/70A
- [Flycolor Raptor S-Tower manual (Foxtech PDF)](https://www.foxtechfpv.com/product/ESC%20and%20FC/S-TowerBLHeli-Smanual.pdf) — EFM8BB21F16 ESC MCU, BLHeli_S feature set
- [Betaflight hardware wiki](https://betaflight.com/docs/wiki/getting-started/hardware) — MCU/gyro guidance, F405 status, AT32F435 pin-compatibility
- [betaflight/config README](https://github.com/betaflight/config) — custom target workflow, TIMER_MAP procedure
- [OMNIBUSF4 config.h](https://github.com/betaflight/config/blob/master/configs/OMNIBUSF4/config.h) — motor pins PB0/PB1/PA3/PA2 precedent + TIMER_PIN_MAP
- [STM32F405RGT6 @ LCSC C15742](https://www.lcsc.com/product-detail/C15742.html) · [JLCPCB part page](https://jlcpcb.com/partdetail/Stmicroelectronics-STM32F405RGT6/C15742)
- [ICM-42688-P @ TDK](https://invensense.tdk.com/products/motion-tracking/6-axis/icm-42688-p) · [LCSC C1850418](https://www.lcsc.com/product-detail/C1850418.html) — active, stocked
- [TLV73333P @ LCSC C134139](https://www.lcsc.com/product-detail/C134139.html)
- [AT32F435RGT7 @ LCSC C3029577](https://www.lcsc.com/product-detail/C3029577.html)
- [ST AN4879 — USB hardware guidelines](https://www.st.com/resource/en/application_note/an4879-introduction-to-usb-hardware-and-pcb-guidelines-using-stm32-mcus-stmicroelectronics.pdf) — no external series resistors for FS
- STM32F405 datasheet DS8626 (VCAP, PC13 drive limits) · ST AN2606 (boot modes, BOOT1)

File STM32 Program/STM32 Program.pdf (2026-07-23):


23/07/2026

STM32 Program Project
Configuration Report

## 1. Description

### 1.1. Project

Project Name | STM32 Program
Board Name | custom
Generated with: | STM32CubeMX 6.18.0
Date | 07/23/2026

### 1.2. MCU

MCU Series | STM32F4
MCU Line | STM32F405/415
MCU name | STM32F405RGTx
MCU Package | LQFP64
MCU Pin number | 64

### 1.3. Core(s) information

Core(s) | Arm Cortex-M4

## 2. Pinout Configuration

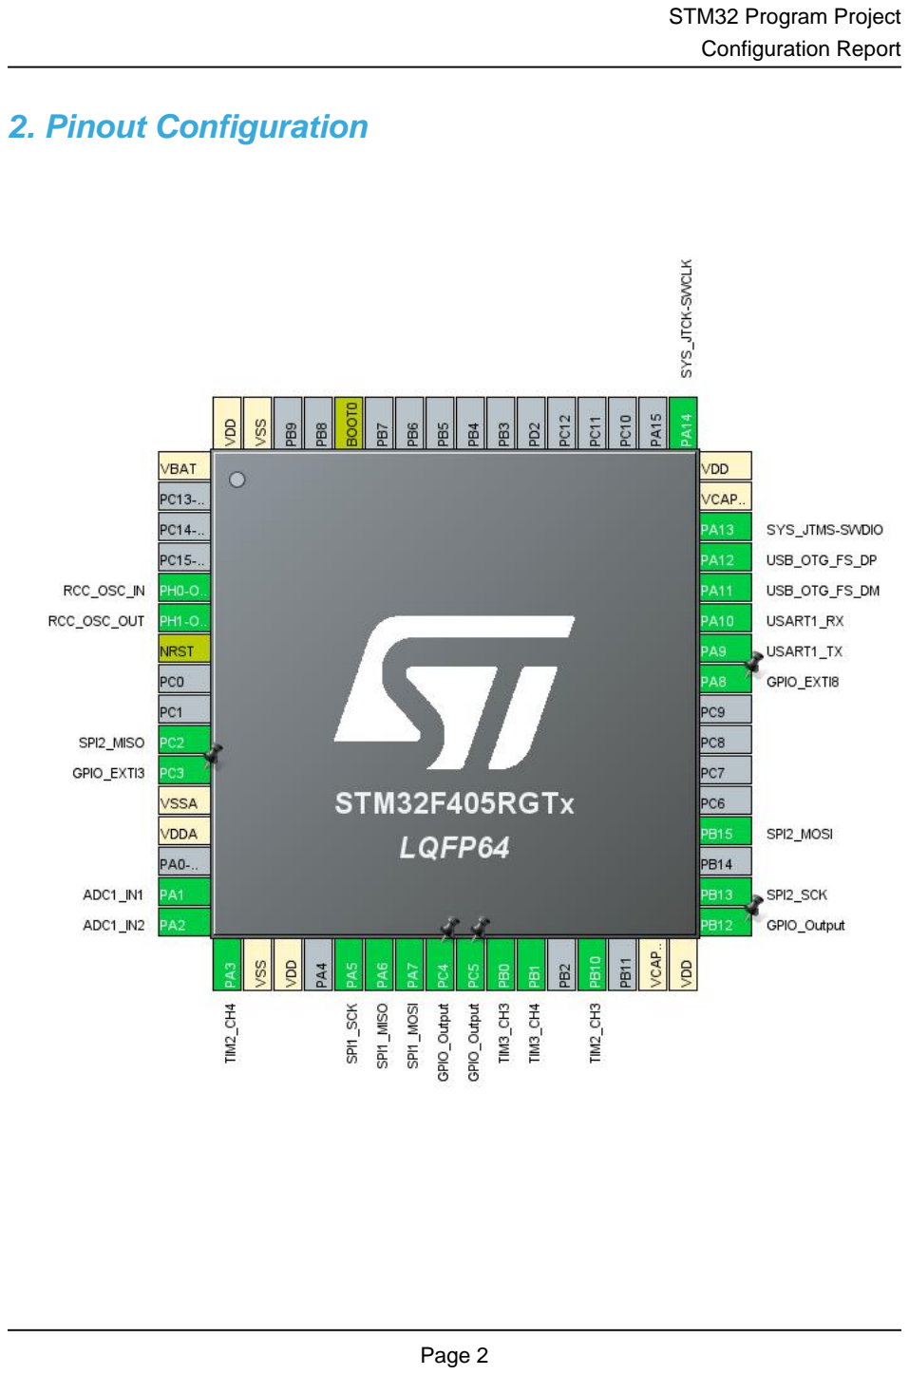
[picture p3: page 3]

## 3. Pins Configuration

Pin Number LQFP64 | Pin Name (function after reset) | Pin Type | Alternate Function(s) | Label
1 | VBAT | Power
5 | PH0-OSC_IN | I/O | RCC_OSC_IN
6 | PH1-OSC_OUT | I/O | RCC_OSC_OUT
7 | NRST | Reset
10 | PC2 | I/O | SPI2_MISO
11 | PC3 | I/O | GPIO_EXTI3
12 | VSSA | Power
13 | VDDA | Power
15 | PA1 | I/O | ADC1_IN1
16 | PA2 | I/O | ADC1_IN2
17 | PA3 | I/O | TIM2_CH4
18 | VSS | Power
19 | VDD | Power
21 | PA5 | I/O | SPI1_SCK
22 | PA6 | I/O | SPI1_MISO
23 | PA7 | I/O | SPI1_MOSI
24 | PC4 * | I/O | GPIO_Output
25 | PC5 * | I/O | GPIO_Output
26 | PB0 | I/O | TIM3_CH3
27 | PB1 | I/O | TIM3_CH4
29 | PB10 | I/O | TIM2_CH3
31 | VCAP_1 | Power
32 | VDD | Power
33 | PB12 * | I/O | GPIO_Output
34 | PB13 | I/O | SPI2_SCK
36 | PB15 | I/O | SPI2_MOSI
41 | PA8 | I/O | GPIO_EXTI8
42 | PA9 | I/O | USART1_TX
43 | PA10 | I/O | USART1_RX
44 | PA11 | I/O | USB_OTG_FS_DM
45 | PA12 | I/O | USB_OTG_FS_DP
46 | PA13 | I/O | SYS_JTMS-SWDIO
47 | VCAP_2 | Power
48 | VDD | Power
49 | PA14 | I/O | SYS_JTCK-SWCLK
60 | BOOT0 | Boot

Pin Number LQFP64 | Pin Name (function after reset) | Pin Type | Alternate Function(s) | Label
63 | VSS | Power
64 | VDD | Power

* The pin is affected with an I/O function

## 4. Clock Tree Configuration

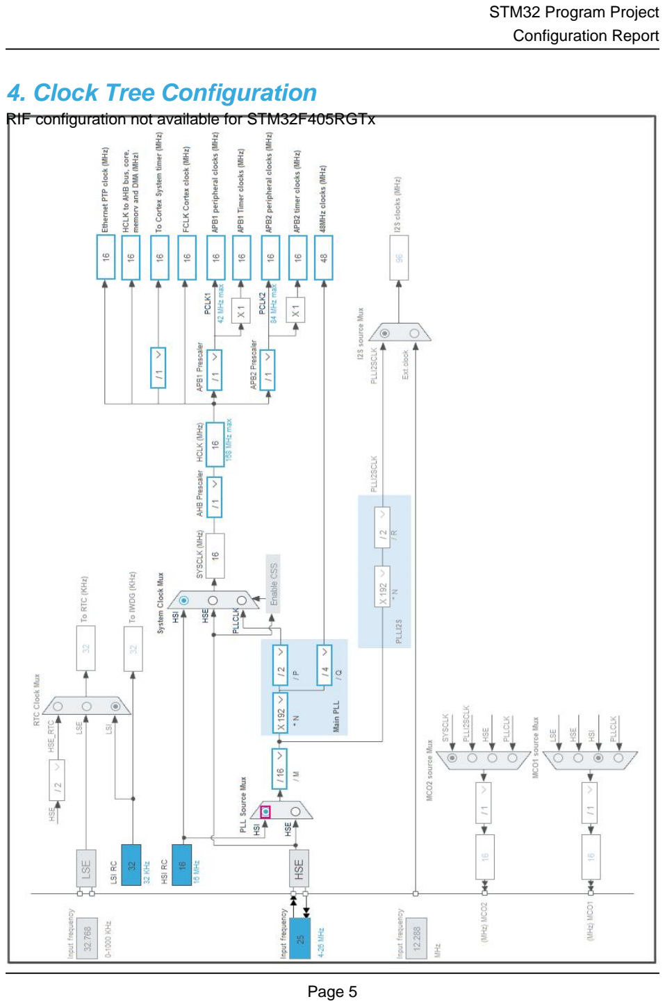
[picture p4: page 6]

RIF configuration not available for STM32F405RGTx

## 1. Power Consumption Calculator report

### 1.1. Microcontroller Selection

Series | STM32F4
Line | STM32F405/415
MCU | STM32F405RGTx
Datasheet | DS8626_Rev8

### 1.2. Parameter Selection

Temperature | 25
Vdd | 3.3

### 1.3. Battery Selection

Battery | Li-SOCL2(A3400)
Capacity | 3400.0 mAh
Self Discharge | 0.08 %/month
Nominal Voltage | 3.6 V
Max Cont Current | 100.0 mA
Max Pulse Current | 200.0 mA
Cells in series | 1
Cells in parallel | 1

### 1.4. Sequence

Step | Step1 | Step2
Mode | RUN | STOP
Vdd | 3.3 | 3.3
Voltage Source | Battery | Battery
Range | Scale1-High | No Scale
Fetch Type | FLASH | n/a
CPU Frequency | 168 MHz | 0 Hz
Clock Configuration | HSE PLL | Regulator_LP Flash-PwrDwn
Clock Source Frequency | 4 MHz | 0 Hz
Peripherals
Additional Cons. | 0 mA | 0 mA
Average Current | 46 mA | 280 µA
Duration | 0.1 ms | 0.9 ms
DMIPS | 210.0 | 0.0
Ta Max | 98.02 | 104.96
Category | In DS Table | In DS Table

### 1.5. Results

Sequence Time | 1 ms | Average Current | 4.85 mA
Battery Life | 29 days, 4 hours | Average DMIPS | 210.0 DMIPS

### 1.6. Chart

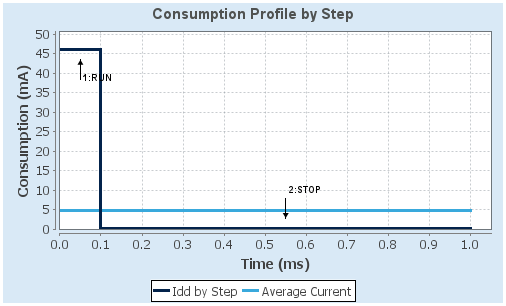
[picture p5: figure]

## 2. Software Project

### 2.1. Project Settings

Name | Value
Project Name | STM32 Program
Project Folder | D:\Drone\drone_PCB\STM32 Program
Toolchain / IDE | EWARM V8.50
Firmware Package Name and Version | STM32Cube FW_F4 V1.28.3
Application Structure | Advanced
Generate Under Root | No
Do not generate the main() | No
Minimum Heap Size | 0x200
Minimum Stack Size | 0x400

### 2.2. Code Generation Settings

Name | Value
STM32Cube MCU packages and embedded software | Copy all used libraries into the project folder
Generate peripheral initialization as a pair of '.c/.h' files | No
Backup previously generated files when re-generating | No
Keep User Code when re-generating | Yes
Delete previously generated files when not re-generated | Yes
Set all free pins as analog (to optimize the power consumption) | No
Enable Full Assert | No

### 2.3. Advanced Settings - Generated Function Calls

Rank | Function Name | Peripheral Instance Name
1 | SystemClock_Config | RCC
2 | MX_GPIO_Init | GPIO
3 | MX_ADC1_Init | ADC1
4 | MX_SPI1_Init | SPI1
5 | MX_SPI2_Init | SPI2
6 | MX_TIM2_Init | TIM2
7 | MX_TIM3_Init | TIM3
8 | MX_USART1_UART_Init | USART1
9 | MX_USB_OTG_FS_PCD_Init | USB_OTG_FS

## 3. Peripherals and Middlewares Configuration

### 3.1. ADC1

mode: IN1
mode: IN2
3.1.1. Parameter Settings:

ADCs_Common_Settings:

Mode | Independent mode
ADC_Settings:
Clock Prescaler | PCLK2 divided by 2
Resolution | 12 bits (15 ADC Clock cycles)
Data Alignment | Right alignment
Scan Conversion Mode | Disabled
Continuous Conversion Mode | Disabled
Discontinuous Conversion Mode | Disabled
DMA Continuous Requests | Disabled
End Of Conversion Selection | EOC flag at the end of single channel conversion
ADC_Regular_ConversionMode:
Number Of Conversion | 1
External Trigger Conversion Source | Regular Conversion launched by software
External Trigger Conversion Edge | None
Rank | 1
Channel | Channel 1
Sampling Time | 3 Cycles
ADC_Injected_ConversionMode:
Number Of Conversions | 0
WatchDog:
Enable Analog WatchDog Mode | false

### 3.2. RCC

High Speed Clock (HSE): Crystal/Ceramic Resonator
3.2.1. Parameter Settings:

System Parameters:

VDD voltage (V) | 3.3
Instruction Cache | Enabled
Prefetch Buffer | Enabled
Data Cache | Enabled

Flash Latency(WS) | 0 WS (1 CPU cycle)
RCC Parameters:
HSI Calibration Value | 16
HSE Startup Timout Value (ms) | 100
LSE Startup Timout Value (ms) | 5000
Power Parameters:
Power Regulator Voltage Scale | Power Regulator Voltage Scale 1

### 3.3. SPI1

Mode: Full-Duplex Master
3.3.1. Parameter Settings:

Basic Parameters:

Frame Format | Motorola
Data Size | 8 Bits
First Bit | MSB First
Clock Parameters:
Prescaler (for Baud Rate) | 2
Baud Rate | 8.0 MBits/s *
Clock Polarity (CPOL) | Low
Clock Phase (CPHA) | 1 Edge
Advanced Parameters:
CRC Calculation | Disabled
NSS Signal Type | Software

### 3.4. SPI2

Mode: Full-Duplex Master
3.4.1. Parameter Settings:

Basic Parameters:

Frame Format | Motorola
Data Size | 8 Bits
First Bit | MSB First
Clock Parameters:
Prescaler (for Baud Rate) | 2
Baud Rate | 8.0 MBits/s *
Clock Polarity (CPOL) | Low

Clock Phase (CPHA) | 1 Edge
Advanced Parameters:
CRC Calculation | Disabled
NSS Signal Type | Software

### 3.5. SYS

Debug: Serial Wire
Timebase Source: SysTick

### 3.6. TIM2

Channel3: PWM Generation CH3 Channel4: PWM Generation CH4
3.6.1. Parameter Settings:

Counter Settings:

Prescaler (PSC - 16 bits value) | 0
Counter Mode | Up
Counter Period (AutoReload Register - 32 bits value ) | 4294967295
Internal Clock Division (CKD) | No Division
auto-reload preload | Disable
Trigger Output (TRGO) Parameters:
Master/Slave Mode (MSM bit) | Disable (Trigger input effect not delayed)
Trigger Event Selection | Reset (UG bit from TIMx_EGR)
PWM Generation Channel 3:
Mode | PWM mode 1
Pulse (32 bits value) | 0
Output compare preload | Enable
Fast Mode | Disable
CH Polarity | High
PWM Generation Channel 4:
Mode | PWM mode 1
Pulse (32 bits value) | 0
Output compare preload | Enable
Fast Mode | Disable
CH Polarity | High

### 3.7. TIM3

Channel3: PWM Generation CH3 Channel4: PWM Generation CH4
3.7.1. Parameter Settings:

Counter Settings:

Prescaler (PSC - 16 bits value) | 0
Counter Mode | Up
Counter Period (AutoReload Register - 16 bits value ) | 65535
Internal Clock Division (CKD) | No Division
auto-reload preload | Disable
Trigger Output (TRGO) Parameters:
Master/Slave Mode (MSM bit) | Disable (Trigger input effect not delayed)
Trigger Event Selection | Reset (UG bit from TIMx_EGR)
PWM Generation Channel 3:
Mode | PWM mode 1
Pulse (16 bits value) | 0
Output compare preload | Enable
Fast Mode | Disable
CH Polarity | High
PWM Generation Channel 4:
Mode | PWM mode 1
Pulse (16 bits value) | 0
Output compare preload | Enable
Fast Mode | Disable
CH Polarity | High

### 3.8. USART1

Mode: Asynchronous
3.8.1. Parameter Settings:

Basic Parameters:

Baud Rate | 115200
Word Length | 8 Bits (including Parity)
Parity | None
Stop Bits | 1
Advanced Parameters:
Data Direction | Receive and Transmit
Over Sampling | 16 Samples

### 3.9. USB_OTG_FS

Mode: Device_Only
3.9.1. Parameter Settings:
Speed | Device Full Speed 12MBit/s
Low power | Disabled
Link Power Management | Disabled
VBUS sensing | Disabled
Signal start of frame | Disabled

* User modified value

## 4. System Configuration

### 4.1. GPIO configuration

IP | Pin | Signal | GPIO mode | GPIO pull/up pull down

Max
Speed

User Label

ADC1 | PA1 | ADC1_IN1 | Analog mode | No pull-up and no pull-down | n/a
| PA2 | ADC1_IN2 | Analog mode | No pull-up and no pull-down | n/a
RCC | PH0- OSC_IN | RCC_OSC_IN | n/a | n/a | n/a
| PH1- OSC_OUT | RCC_OSC_OUT | n/a | n/a | n/a
SPI1 | PA5 | SPI1_SCK | Alternate Function Push Pull | No pull-up and no pull-down | Very High
*
| PA6 | SPI1_MISO | Alternate Function Push Pull | No pull-up and no pull-down | Very High
*
| PA7 | SPI1_MOSI | Alternate Function Push Pull | No pull-up and no pull-down | Very High
*
SPI2 | PC2 | SPI2_MISO | Alternate Function Push Pull | No pull-up and no pull-down | Very High
*
| PB13 | SPI2_SCK | Alternate Function Push Pull | No pull-up and no pull-down | Very High
*
| PB15 | SPI2_MOSI | Alternate Function Push Pull | No pull-up and no pull-down | Very High
*
SYS | PA13 | SYS_JTMS- SWDIO | n/a | n/a | n/a
| PA14 | SYS_JTCK- SWCLK | n/a | n/a | n/a
TIM2 | PA3 | TIM2_CH4 | Alternate Function Push Pull | No pull-up and no pull-down | Low
| PB10 | TIM2_CH3 | Alternate Function Push Pull | No pull-up and no pull-down | Low
TIM3 | PB0 | TIM3_CH3 | Alternate Function Push Pull | No pull-up and no pull-down | Low
| PB1 | TIM3_CH4 | Alternate Function Push Pull | No pull-up and no pull-down | Low
USART1 | PA9 | USART1_TX | Alternate Function Push Pull | No pull-up and no pull-down | Very High
*
| PA10 | USART1_RX | Alternate Function Push Pull | No pull-up and no pull-down | Very High
*
USB_OTG_ FS | PA11 | USB_OTG_FS_ DM | Alternate Function Push Pull | No pull-up and no pull-down | Very High
*
| PA12 | USB_OTG_FS_ DP | Alternate Function Push Pull | No pull-up and no pull-down | Very High
*
GPIO | PC3 | GPIO_EXTI3 | External Interrupt Mode with | No pull-up and no pull-down | n/a

IP | Pin | Signal | GPIO mode | GPIO pull/up pull down | Max Speed | User Label
| | | Rising edge trigger detection
| PC4 | GPIO_Output | Output Push Pull | No pull-up and no pull-down | Low
| PC5 | GPIO_Output | Output Push Pull | No pull-up and no pull-down | Low
| PB12 | GPIO_Output | Output Push Pull | No pull-up and no pull-down | Low
| PA8 | GPIO_EXTI8 | External Interrupt Mode with Rising edge trigger detection | No pull-up and no pull-down | n/a

### 4.2. DMA configuration

nothing configured in DMA service

### 4.3. NVIC configuration

4.3.1. NVIC
Interrupt Table | Enable | Preenmption Priority | SubPriority
Non maskable interrupt | true | 0 | 0
Hard fault interrupt | true | 0 | 0
Memory management fault | true | 0 | 0
Pre-fetch fault, memory access fault | true | 0 | 0
Undefined instruction or illegal state | true | 0 | 0
System service call via SWI instruction | true | 0 | 0
Debug monitor | true | 0 | 0
Pendable request for system service | true | 0 | 0
System tick timer | true | 15 | 0
PVD interrupt through EXTI line 16 | unused
Flash global interrupt | unused
RCC global interrupt | unused
EXTI line3 interrupt | unused
ADC1, ADC2 and ADC3 global interrupts | unused
EXTI line[9:5] interrupts | unused
TIM2 global interrupt | unused
TIM3 global interrupt | unused
SPI1 global interrupt | unused
SPI2 global interrupt | unused
USART1 global interrupt | unused
USB On The Go FS global interrupt | unused
FPU global interrupt | unused
4.3.2. NVIC Code generation
Enabled interrupt Table | Select for init sequence ordering | Generate IRQ handler | Call HAL handler
Non maskable interrupt | false | true | false
Hard fault interrupt | false | true | false
Memory management fault | false | true | false
Pre-fetch fault, memory access fault | false | true | false
Undefined instruction or illegal state | false | true | false
System service call via SWI instruction | false | true | false
Debug monitor | false | true | false
Pendable request for system service | false | true | false
System tick timer | false | true | true

* User modified value

## 5. System Views

5.1. Category view
5.1.1. Current

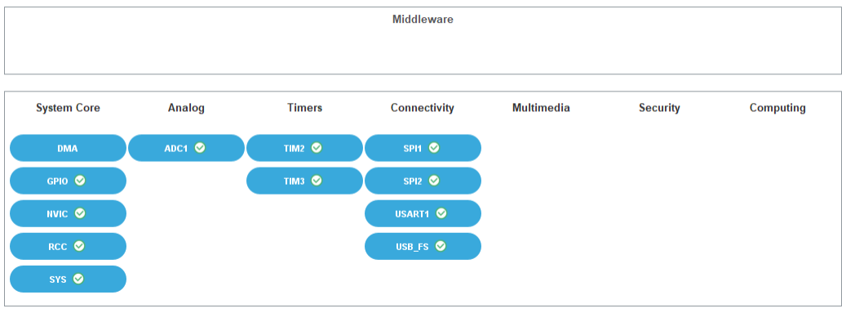
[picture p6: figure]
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

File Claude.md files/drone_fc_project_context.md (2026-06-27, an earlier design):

# Custom Drone Flight Controller PCB - Revised Project Context

## Project Goal
Design a custom flight controller PCB built around the STM32F405RGT6, compatible with Betaflight firmware. The board connects to an existing Flycolor Raptor BLS-04 4-in-1 ESC via its original cable. 

## Why This Approach
- STM32F405 is the industry standard FC chip.
- Directly relevant to drone/embedded companies.
- Real firmware work: writing a custom Betaflight target file.
- More resume impact than a module-based approach.

---

## Hardware Stack

### ESC
- **Flycolor Raptor BLS-04** 4-in-1 ESC
- 3-6S LiPo input, 65A continuous / 70A burst
- BLHeli_S firmware
- Supports DSHOT150/300/600 and OneShot125
- **No onboard BEC**
- Connects to FC via 10-pin JST SH1.0 cable

### Power
- **Matek MBEC6S** external buck converter (already built)
  - Input: 6-30V (raw LiPo)
  - Output: 5V, 1.5A continuous / 2.5A burst
- **On FC board:** AP2112K-3.3 LDO (5V in → 3.3V out). Chosen for strict stability with low-ESR ceramic capacitors.

### Power Chain
`LiPo → BLS-04 ESC (raw LiPo passthrough) → Matek MBEC6S → 5V → FC board → AP2112K-3.3 → 3.3V → STM32 + IMU`

---

## MCU: STM32F405RGT6

- 168MHz Cortex-M4 with FPU
- LQFP-100 package, 0.5mm pitch
- Native Betaflight support
- Required support circuitry:
  - 8MHz external crystal (clock source)
  - Decoupling caps on every VDD/VDDA pin (strictly routed: Plane → Cap → Pin)
  - BOOT0 pin with 10k pull-down + button to 3.3V
  - NRST button to GND with 100nF cap
  - **22Ω series resistors** on USB D+ and D- lines
  - **VBUS sensing circuit** (voltage divider to GPIO)

---

## ESC Connector & Protection

**JST SH1.0 10-pin female receptacle on FC board**

| Pin | Signal | FC Destination | Protection / Filtering |
|-----|---|---|---|
| 1 | GND | Ground plane | None |
| 2 | GND | Ground plane | None |
| 3 | VBAT | ADC pin (PC1) | 100k/10k divider + **0.1μF cap to GND** |
| 4 | NC | No connection | N/A |
| 5 | Motor 4 | PB1 (TIM3_CH4) | None |
| 6 | Motor 3 | PB0 (TIM3_CH3) | None |
| 7 | Motor 2 | PA3 (TIM2_CH4) | None |
| 8 | Motor 1 | PA2 (TIM2_CH3) | None |
| 9 | CRT (Current) | ADC pin (PC2) | **1kΩ series resistor** + optional 3.3V Zener |
| 10 | NC | No connection | N/A |

---

## Full Pin Assignment Table

| Function | STM32F405 Pin | Notes |
|---|---|---|
| Motor 1 | PA2 | TIM2_CH3, DMA capable for DSHOT |
| Motor 2 | PA3 | TIM2_CH4 |
| Motor 3 | PB0 | TIM3_CH3 |
| Motor 4 | PB1 | TIM3_CH4 |
| IMU SCK | PA5 | SPI1 |
| IMU MISO | PA6 | SPI1 |
| IMU MOSI | PA7 | SPI1 |
| IMU CS | PC4 | Any GPIO |
| IMU INT | PC3 | Any GPIO, interrupt input |
| Flash SCK | PB13 | SPI2 |
| Flash MISO | PB14 | SPI2 |
| Flash MOSI | PB15 | SPI2 |
| Flash CS | PB12 | Any GPIO |
| USB D- | PA11 | USB FS (Requires 22Ω series resistor) |
| USB D+ | PA12 | USB FS (Requires 22Ω series resistor) |
| **VBUS Sense** | **PC0** | **Detects USB connection (10k/10k divider from 5V USB)** |
| UART1 TX | PA9 | Receiver input |
| UART1 RX | PA10 | **ELRS Recommended** (SBUS requires external hardware inverter) |
| UART3 TX | PB10 | ESC telemetry (optional) |
| UART3 RX | PB11 | |
| VBAT ADC | PC1 | ADC12_IN11 (Requires 0.1μF bypass cap) |
| Current ADC | PC2 | ADC12_IN12 (Requires 1kΩ series protection resistor) |
| Buzzer | PC5 | GPIO → MOSFET → buzzer |
| Status LED | PC13 | GPIO |

---

## Full Component List

### MCU Support
- STM32F405RGT6 (LQFP-100)
- 8MHz crystal + 2x 22pF load caps
- Decoupling: 1uF + 100nF on each VDD pin, 1uF + 10nF on VDDA
- USB Series Resistors: 2x 22Ω (0402 or 0603)
- BOOT0 / NRST tactile buttons

### Power
- **AP2112K-3.3** LDO (SOT-23-5)
- 10uF + 100nF input caps on LDO
- 10uF + 100nF output caps on LDO

### IMU
- **ICM-42688-P** (SPI, modern Betaflight standard, currently manufactured)
- 100nF decoupling on VDD and VDDIO
- Mount at center of board, away from switching noise

### Blackbox
- W25Q128JVSIQ SPI NOR flash (16MB, SPI2)
- 100nF decoupling

### Connectors
- JST SH1.0 10-pin female (ESC interface)
- 3-pin 2.54mm header: UART1 RX/TX/GND (Receiver)
- 3-pin 2.54mm header: UART3 RX/TX/GND (ESC telemetry)
- USB-C connector with 5.1k resistors on CC1 and CC2 to GND

### Misc & Protection
- Passive buzzer + 2N7002 MOSFET + 1N4148 flyback diode
- Status LED + 330Ω series resistor
- VBAT divider: 100kΩ + 10kΩ + **0.1μF capacitor**
- Current sense protection: **1kΩ series resistor**
- **VBUS divider**: 10kΩ + 10kΩ (5V USB to PC0)

---
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

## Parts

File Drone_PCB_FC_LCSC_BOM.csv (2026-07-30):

Comment | Designator | Footprint | Qty | LCSC Part # | Notes
STM32F405RGT6 | U4 | LQFP-64_10x10mm_P0.5mm | 1 | C15742 | MCU. Verified.
BMI270 | U7 | LGA-14_L3.0-W2.5-P0.50-BR | 1 | C2836813 | IMU. DESIGNATOR IS U7 (schematic + PCB + production files all say U7; this line previously said U6 in error). REPLACES ICM-42605 (C2655099) / ICM-42688-P (C1850418) — entire 426xx family is reel-only or OOS in small qty. Bosch BMI270 is in stock at LCSC at qty 1, ~$0.82-1.79. WARNING: DIFFERENT PINOUT from the 426xx — footprint changed to ...-BR and every IMU net was re-wired. Wiring (4-wire SPI, Secondary=None, datasheet Table 22 p.145): SCx(13)=SPI1 SCK/PA5, SDx(14)=MOSI/PA7, SDO(1)=MISO/PA6, CSB(12)=CS/PC4 + 10k pullup to VDDIO, INT1(4)=PC3/EXTI3. VDD(8)=+3V3_IMU +100nF, VDDIO(5)=+3V3 +100nF, GND(7)+GNDIO(6)=GND. ASDx(2)/ASCx(3)->VDDIO; OCSB(10)/OSDO(11)/INT2(9)=DNC. Decoupling is just 100nF x2 (NOT the 2.2uF/10nF combo the 426xx wanted). Betaflight gyro define = BMI270.
GD25Q16ETIGR | U3 | SOIC-8_5.3x5.3mm_P1.27mm | 1 | C2904431 | *** AS-ORDERED / AS-FITTED PART. 16 Mbit = 2 MB, NOT 16 MB. This is 1/8th the intended blackbox capacity — the 128 Mbit part below was specified but the 16 Mbit part was actually ordered (caught 2026-07-30). DECISION: keeping it. Betaflight supports it with NO firmware change: `USE_FLASH_W25Q128FV` is only a gate that pulls in the generic m25p16 driver via common_post.h, and that driver detects by JEDEC ID at runtime. Our chip is in its table as { 0xC84015, 104, 50, 32, 256 } = 32 sectors x 256 pages x 256 B = 2,097,152 B. Configurator will report 2 MB — that is correct, not a fault. MUST DO at bring-up: `set blackbox_sample_rate = 1/4` (800 Hz logging @ 3.2 kHz PID) or you get only ~22 s of log per erase; at 1/4 you get ~87 s, which is enough for 30-60 s tuning runs but not a whole pack. See betaflight_target/BUILD.md for the full rate table.
BY25Q128ESSIG(T) | U3-ALT | SOIC-8_5.3x5.3mm_P1.27mm | 0 | C22471255 | NOT FITTED — this is what was SPECIFIED but not ordered. Kept as the documented upgrade path: 128 Mbit / 16 MB, ~$0.36. BOYAMICRO BY25Q128ES is NAMED in Betaflight's supported flash list. SOIC-8-208mil = same footprint+pinout as W25Q128 (drop-in). Replaces Winbond C97521/C179171 which hit MOQ 12-14 (~$25-30). Backup: GD25Q128ESIG C2758105 (~$0.83, GigaDevice, also BF-supported). Avoid Puya (not in BF list).
AP2112K-3.3 | U1 | SOT-23-5 | 1 | C51118 | Main 3.3V LDO. Verified.
TLV73333PDBVR | IMU-U2 | SOT-23-5 | 1 | C134139 | IMU-rail 3.3V LDO. Verified.
TPS5450DDAR | U5 | ESOP-8_L4.9-W3.9-EP | 1 | C114425 | Pin-for-pin drop-in for TPS5430DDAR (C9864, OOS). Same DDA/ESOP-8 + pinout + 1.221V ref (10k/3.24k still =5.0V), 5.5-36V in, 5A. All buck passives unchanged. If load >3A, upgrade catch diode D2 to 5A Schottky (SS54). Verified in stock.
USBLC6-2SC6 | U2 | SOT-23-6 | 1 | C7519 | USB ESD (optional). Verified.
TYPE-C-31-M-12 | J2 | USB-C_SMD_TYPE-C-31-M-12 | 1 | C165948 | USB-C receptacle. Verified.
SM10B-SRSS-TB | CN1 | CONN-SMD_10P-P1.00_SM10B-SRSS-TB | 1 | C160409 | JST SH 1.0 10P (ESC). Verified.
SUN-12095-5VPA7.6 | BZ1 | Buzzer_12x9.5RM7.6 | 1 | C360615 | Buzzer. Set DNP if not populating.
8MHz | Y1 | Crystal_SMD_3225-4Pin | 1 | C2682775 | YXC X32258MOB4SI 8MHz 3225. Verified.
15uH | L2 | drone_lib:IND-SMD_L6.0-W6.0_SWPA6045S | 1 | C83374 | Sunlord SWPA6045S150MT 15uH, 6.0x6.0x4.5mm, ~2A Irms / 2.7A Isat, 71mOhm. MOQ 10 = ~$0.70, IN STOCK. Replaces 22uH C354622 (wrong value after 4S change + OOS + MOQ 10 @ $25). FOOTPRINT ACTION: not identical to the old land — new pads are at +/-2.60mm / 2.47x5.02mm vs old +/-2.50mm / 2.20x5.72mm. Import via libs/import_lcsc.py and repoint L2. For near-3A load use Bourns SRN6045TA-150M (C1330797).
600R@100MHz | FB1 | L_0805_2012Metric | 1 | C139475 | Bourns MU2029-600Y ferrite bead 0805. Verified.
SS34 | D2 | D_SMA | 1 | C8678 | MDD SS34 40V 3A Schottky SMA. Verified.
D_Schottky | D3,D4 | D_SMA | 2 | C8678 | Using SS34 (same as D2). Verified.
D_Zener | D1 | D_SOD-123 | 1 | C173413 | 3.3V zener clamp on ESC current-sense line into PC1 (1k series + zener). MDD BZT52C3V3 SOD-123. Verified.
LED | D5,D6 | LED_0805_2012Metric | 2 | C2295 | Hubei KENTO KT-0805R red 0805. Verified.
1uF | C1,C2,C3,C4,C19 | C_0805_2012Metric | 5 | C28323 | Samsung CL21B105KBFNNNE 1uF 50V X7R. Verified.
10uF | C5,C6 | C_1210_3225Metric | 2 | C77102 | Buck Cin, GRM32ER71H106KA12L 50V X7R. QTY CORRECTED 1->2 per locked design. TPS545x input RMS ripple = Iout/2 ~= 1.5A (datasheet 8.2.1.2.2); two caps halve per-part ripple current and lower effective ESR. 1210 is mandatory: 50V rating + DC-bias derating at 16.8V (a small pkg would derate below the 4.7uF datasheet minimum). ACTION: C6 must still be added to the schematic/board — only C5 is currently placed.
220uF | C8 | Capacitor_Tantalum_SMD:CP_EIA-7343-31_Kemet-D | 1 | C242173 | Buck Cout. Panasonic POSCAP 10TPB220M — the EXACT part named in the TPS543x/545x datasheet worked example (8.2.1.2.3.2). 220uF / 10V / ESR 40mOhm @100kHz / 3000mA ripple rating (design needs 143mA). REPLACES C156462 (KEMET T520): that part was 220uF but only 6.3V — too tight on a 5V rail since tantalum-family needs ~2x voltage derating (TI's reference is 10V) — and its 12mOhm ESR sat below the 20-40mOhm band the TPS545x internal compensation assumes, pushing the ESR zero from ~18kHz to ~60kHz past crossover. Case EIA-7343 (2917) 7.3x4.3x3.8mm: same land pattern as before, but 3.8mm tall (was ~2mm) so footprint bumped -20 -> -31; confirm nothing overhangs it.
10nF | C7,C9,C18 | C_0805_2012Metric | 3 | C1710 | MERGED: C7 was '.01uF'=10nF. One is buck BOOT cap. Samsung 50V X7R. Verified.
2.2uF | C10,C12,C13 | C_0805_2012Metric | 3 | C49217 | Two are STM32 VCAP. Fenghua 0805F225M500NT 50V. Verified.
100nF | C11,C20,C24,C25,C26,C27,C29,C30 | C_0805_2012Metric | 8 | C49678 | MERGED: C11 was '.1uF'=100nF. YAGEO 100nF 50V X7R. Verified.
22pF | C21,C22 | C_0805_2012Metric | 2 | C1804 | Crystal load caps. Samsung 22pF 50V C0G. CONFIRM value vs crystal CL. Verified.
4.7uF | C28 | C_0805_2012Metric | 1 | C1779 | Samsung 4.7uF 25V 0805. Verified.
5.1k | R1,R2 | R_0805_2012Metric | 2 | C27834 | USB CC pulldowns. UNI-ROYAL 5.1k 1% 0805. Verified.
10k | R3,R4,R7,R9,R13,R15,R17,R18 | R_0805_2012Metric | 8 | C17414 | UNI-ROYAL 10k 1% 0805. R7 (buck feedback upper) MERGED IN from the separate 0603 line — no electrical reason for a smaller package: it dissipates ~1.4uW (378uA through the 10k/3.24k divider) and sees 3.78V. What actually matters per TPS545x 10.1 is placement: keep R7/R8 close to the VSENSE pin and route the VOUT->VSENSE trace away from the PH node. Both R7 and R8 must be 1% (they set Vout). Verified.
1k | R5 | R_0805_2012Metric | 1 | C17513 | UNI-ROYAL 1k 0805. Verified.
100k | R6 | R_0805_2012Metric | 1 | C17407 | UNI-ROYAL 100k 1% 0805. Verified.
3.24k | R8 | R_0805_2012Metric | 1 | C101657 | Buck feedback R2 (with 10k sets 5.0V). 3.24k 1% 0805. Verified.
470 | R14 | R_0805_2012Metric | 1 | C17710 | UNI-ROYAL 470R 1% 0805. Verified.
330 | R19 | R_0805_2012Metric | 1 | C17630 | UNI-ROYAL 330R 0805. Verified.
Conn_01x05 | J1 | PinHeader_1x05_P2.54mm | 1 |  | 2.54mm header — snap from a 1x40 strip (e.g. C2337) or hand-populate.
Conn_01x04 | J3 | PinHeader_1x04_P2.54mm | 1 |  | 2.54mm header — snap from a 1x40 strip (e.g. C2337) or hand-populate.
SW_Push | SW1,SW2 | SW_PUSH_6mm | 2 |  | BOOT0/NRST tact 6mm THT — pick any 6mm 4-pin tact; hand-solder.

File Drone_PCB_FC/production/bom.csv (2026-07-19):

Designator | Footprint | Quantity | Value | LCSC Part #
BZ1 | Buzzer_12x9.5RM7.6 | 1 | Buzzer
C1, C19, C2, C3, C4 | 0805 | 5 | 1uF
C12, C13 | 0805 | 2 | 2.2uF
C14, C15, C20, C24, C25, C26, C27, C29, C30, C31 | 0805 | 10 | 100nF
C18 | 0805 | 1 | 10nF
C21, C22 | 0805 | 2 | 22pF
C28 | 0805 | 1 | 4.7uF
C5 | 1210 | 1 | 10uF
C7 | 0805 | 1 | .01uF
C8 | CP_EIA-7343-31_Kemet-D | 1 | 220uF
CN1 | CONN-SMD_10P-P1.00_SM10B-SRSS-TB-LF-SN | 1 | SM10B-SRSS-TB | C160409
D1 | D_SOD-123 | 1 | D_Zener
D3, D4, D7, D9 | D_SMA | 4 | D_Schottky
D5, D6 | 0805 | 2 | LED
D8 | D_DO-35_SOD27_P7.62mm_Horizontal | 1 | 1N914
FB1 | 0805 | 1 | 600ohms 100MHz
IMU-U2 | SOT-23-5 | 1 | TLV73333PDBV
J1 | PinHeader_1x05_P2.54mm_Vertical | 1 | Conn_01x05
J2 | USB_C_Receptacle_HRO_TYPE-C-31-M-12 | 1 | USB_C_Receptacle_USB2.0_14P
J3, J4, J5, J6 | PinHeader_1x04_P2.54mm_Vertical | 4 | Conn_01x04
J7 | PinSocket_1x06_P2.54mm_Vertical | 1 | Conn_01x06
L2 | IND-SMD_L6.0-W6.0 | 1 | 15uH | C354622
Q2 | TO-92_Inline | 1 | 2N7000
R1, R2 | 0805 | 2 | 5.1k
R13, R15, R17, R18, R20, R3, R4, R7, R9 | 0805 | 9 | 10k
R14 | 0805 | 1 | 470
R19 | 0805 | 1 | 330
R5 | 0805 | 1 | 1k
R6 | 0805 | 1 | 100k
R8 | 0805 | 1 | 3.24k
SW1, SW2 | SW_PUSH_6mm | 2 | SW_Push
U1 | SOT-23-5 | 1 | AP2112K-3.3
U2 | SOT-23-6 | 1 | USBLC6-2SC6
U3 | SOIC-8_L5.3-W5.3-P1.27-LS8.0-BL | 1 | GD25Q16ETIGR | C2904431
U4 | LQFP-64_10x10mm_P0.5mm | 1 | STM32F405RGTx
U5 | ESOP-8_L4.9-W3.9-P1.27-LS6.0-TL-EP | 1 | TPS5430DDAR | C9864
U7 | LGA-14_L3.0-W2.5-P0.50-BR | 1 | BMI270 | C2836813
Y1 | Crystal_SMD_3225-4Pin_3.2x2.5mm | 1 | 8MHz

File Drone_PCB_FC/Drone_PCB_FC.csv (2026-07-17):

Reference | Qty | Value | DNP | Exclude from BOM | Exclude from Board | Footprint | Datasheet
BZ1 | 1 | Buzzer |  |  |  | Buzzer_Beeper:Buzzer_12x9.5RM7.6
C1,C2,C3,C4,C19 | 5 | 1uF |  |  |  | Capacitor_SMD:C_0805_2012Metric
C5 | 1 | 10uF |  |  |  | Capacitor_SMD:C_1210_3225Metric
C7 | 1 | .01uF |  |  |  | Capacitor_SMD:C_0805_2012Metric
C8 | 1 | 220uF |  |  |  | Capacitor_Tantalum_SMD:CP_EIA-7343-31_Kemet-D
C9,C18 | 2 | 10nF |  |  |  | Capacitor_SMD:C_0805_2012Metric
C10,C12,C13 | 3 | 2.2uF |  |  |  | Capacitor_SMD:C_0805_2012Metric
C11 | 1 | .1uF |  |  |  | Capacitor_SMD:C_0805_2012Metric
C20,C24,C25,C26,C27,C29,C30 | 7 | 100nF |  |  |  | Capacitor_SMD:C_0805_2012Metric
C21,C22 | 2 | 22pF |  |  |  | Capacitor_SMD:C_0805_2012Metric
C28 | 1 | 4.7uF |  |  |  | Capacitor_SMD:C_0805_2012Metric
CN1 | 1 | SM10B-SRSS-TB |  |  |  | drone_lib:CONN-SMD_10P-P1.00_SM10B-SRSS-TB-LF-SN | https://lcsc.com/product-detail/Others_JST-Sales-America__JST-Sales-America-SM10B-SRSS-TB-LF-SN_C160409.html
D1 | 1 | D_Zener |  |  |  | Diode_SMD:D_SOD-123
D2 | 1 | SS34 |  |  |  | Diode_SMD:D_SMA | https://www.vishay.com/docs/88751/ss32.pdf
D3,D4 | 2 | D_Schottky |  |  |  | Diode_SMD:D_SMA
D5 | 1 | LED |  |  |  | LED_SMD:LED_0805_2012Metric
D6 | 1 | LED |  |  |  | LED_SMD:LED_0805_2012Metric_Pad1.15x1.40mm_HandSolder
FB1 | 1 | 600ohms 100MHz |  |  |  | Inductor_SMD:L_0805_2012Metric
IMU-U2 | 1 | TLV73333PDBV |  |  |  | Package_TO_SOT_SMD:SOT-23-5 | http://www.ti.com/lit/ds/symlink/tlv733p.pdf
J1 | 1 | Conn_01x05 |  |  |  | Connector_PinHeader_2.54mm:PinHeader_1x05_P2.54mm_Vertical
J2 | 1 | USB_C_Receptacle_USB2.0_14P |  |  |  | Connector_USB:USB_C_Receptacle_HRO_TYPE-C-31-M-12 | https://www.usb.org/sites/default/files/documents/usb_type-c.zip
J3 | 1 | Conn_01x04 |  |  |  | Connector_PinHeader_2.54mm:PinHeader_1x04_P2.54mm_Vertical
L2 | 1 | 15uH |  |  |  | drone_lib:IND-SMD_L6.0-W6.0
R1,R2 | 2 | 5.1k |  |  |  | Resistor_SMD:R_0805_2012Metric
R3,R4,R9,R13,R15,R17,R18 | 7 | 10k |  |  |  | Resistor_SMD:R_0805_2012Metric
R5 | 1 | 1k |  |  |  | Resistor_SMD:R_0805_2012Metric
R6 | 1 | 100k |  |  |  | Resistor_SMD:R_0805_2012Metric
R7 | 1 | 10k |  |  |  | Resistor_SMD:R_0603_1608Metric
R8 | 1 | 3.24k |  |  |  | Resistor_SMD:R_0805_2012Metric
R14 | 1 | 470 |  |  |  | Resistor_SMD:R_0805_2012Metric
R19 | 1 | 330 |  |  |  | Resistor_SMD:R_0805_2012Metric
SW1,SW2 | 2 | SW_Push |  |  |  | Button_Switch_THT:SW_PUSH_6mm
U1 | 1 | AP2112K-3.3 |  |  |  | Package_TO_SOT_SMD:SOT-23-5 | https://www.diodes.com/assets/Datasheets/AP2112.pdf
U2 | 1 | USBLC6-2SC6 |  |  |  | Package_TO_SOT_SMD:SOT-23-6 | https://www.st.com/resource/en/datasheet/usblc6-2.pdf
U3 | 1 | W25Q128JVSIQTR |  |  |  | drone_lib:SOIC-8_L5.3-W5.3-P1.27-LS8.0-BL | https://lcsc.com/product-detail/FLASH_W25Q128JVSIQTR_C97521.html
U4 | 1 | STM32F405RGTx |  |  |  | Package_QFP:LQFP-64_10x10mm_P0.5mm | https://www.st.com/resource/en/datasheet/stm32f405rg.pdf
U5 | 1 | TPS5430DDAR |  |  |  | drone_lib:ESOP-8_L4.9-W3.9-P1.27-LS6.0-TL-EP | https://lcsc.com/product-detail/DC-DC-Converters_TI_TPS5430DDAR_TPS5430DDAR_C9864.html
U6 | 1 | ICM-42605 |  |  |  | drone_lib:LGA-14_L3.0-W2.5-P0.50-TL | https://www.lcsc.com/datasheet/C2655099.pdf
Y1 | 1 | 8MHz |  |  |  | Crystal:Crystal_SMD_3225-4Pin_3.2x2.5mm

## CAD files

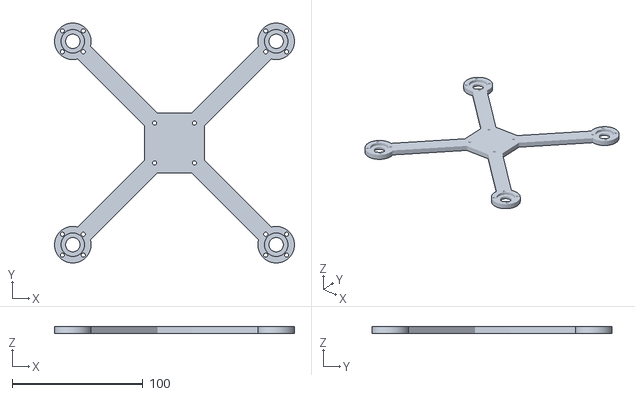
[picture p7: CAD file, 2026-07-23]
5inch_frame_bottom.stl
183.6 x 183.6 x 5.00

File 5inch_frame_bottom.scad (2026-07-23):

// ============================================================
//  Basic 5" FPV frame — bottom plate
//  Parametric. Open in OpenSCAD (free), change the numbers in the
//  PARAMETERS block, press F5 to preview / F6 to render, then
//  File > Export > STL.
//  Built to fit: 30.5x30.5 M3 stack (your FC+ESC), 16x16 M3 motors.
//  Motor pads have a thinned recess in the center (keeps full
//  thickness only around the screw holes) to save weight.
// ============================================================

/* [PARAMETERS] */
wheelbase   = 220;   // motor-to-motor diagonal (mm). 5" freestyle ~ 210-225
plate_th    = 5;     // plate thickness (mm)
arm_w       = 14;    // arm width (mm)
body        = 46;    // central body square side (mm)
pad_r       = 14;    // motor mount pad radius (mm)
stack       = 30.5;  // FC/ESC stack hole spacing (square, mm)
motor_pat   = 16;    // motor bolt pattern (square, mm)
m3          = 3.2;   // M3 clearance hole diameter
motor_bore  = 11;    // center bore at each motor (bell + wires)
pocket_r    = 9;     // radius of thinned recess in motor pad center
pocket_dep  = 2.5;   // recess depth (leaves plate_th - pocket_dep floor)
$fn         = 64;

off = wheelbase/2/sqrt(2);                 // true-X motor offset
motors = [[off,off],[-off,off],[-off,-off],[off,-off]];

module profile2d() {                        // flat outline + through holes
    difference() {
        union() {
            square([body,body], center=true);           // central body
            for (m=motors) translate(m) circle(r=pad_r); // motor pads
            for (m=motors)                                // arms (center -> pad)
                translate([m[0]/2, m[1]/2])
                    rotate(atan2(m[1],m[0]))
                        square([norm(m)+8, arm_w], center=true);
        }
        for (sx=[stack/2,-stack/2], sy=[stack/2,-stack/2]) // stack M3
            translate([sx,sy]) circle(d=m3);
        for (m=motors) {                                   // motor bore + 16x16 M3
            translate(m) circle(d=motor_bore);
            for (dx=[motor_pat/2,-motor_pat/2], dy=[motor_pat/2,-motor_pat/2])
                translate([m[0]+dx, m[1]+dy]) circle(d=m3);
        }
    }
}

difference() {
    linear_extrude(plate_th) profile2d();
    // thinned recess in each motor pad (top face)
    for (m=motors)
        translate([m[0], m[1], plate_th - pocket_dep])
            cylinder(r=pocket_r, h=pocket_dep + 1);
}

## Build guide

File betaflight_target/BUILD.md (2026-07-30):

# ETHANF405 — build, flash, and bring-up

Everything you need to turn `ETHANF405/config.h` into a `.hex` and get your board
flying. Written assuming you've never built Betaflight before.

The board isn't in Configurator's dropdown (it's custom), so you can't "download
firmware" for it — you compile your own `.hex` from the config in this folder,
then flash that file. Do the build now, while you wait for parts, so bring-up day
is just flash-and-go.

---

## 1. Set up the build environment (one time)

Betaflight builds cleanly on Linux. On Windows the least-painful path is **WSL2**
(a real Ubuntu inside Windows). macOS and native Linux work the same way from
step 1.2.

### 1.1 Windows only — install WSL
In an **Administrator** PowerShell:
```powershell
wsl --install
```
Reboot if it asks, let it finish setting up Ubuntu, and pick a username/password.
From now on, run everything in the **Ubuntu** terminal, not PowerShell.

### 1.2 Install the basic tools
```bash
sudo apt update
sudo apt install -y git make curl
```
You do **not** need to hunt down an ARM compiler — Betaflight downloads the exact
one it wants into its own `tools/` folder on the first build.

---

## 2. Get the source and build (one time, then repeat on any config change)

```bash
# 2.1 clone Betaflight firmware
git clone https://github.com/betaflight/betaflight.git
cd betaflight

# 2.2 pull in the configs (creates src/config/…) and the ARM toolchain
make configs
make arm_sdk_install
```

Now drop your target in and build it:
```bash
# 2.3 copy your custom config into the config tree
mkdir -p src/config/configs/ETHANF405
cp /path/to/betaflight_target/ETHANF405/config.h src/config/configs/ETHANF405/config.h

# 2.4 build
make ETHANF405
```

If it succeeds you'll get a file like:
```
obj/betaflight_<version>_ETHANF405.hex
```
**That `.hex` is your firmware.** Copy it somewhere easy to find on the Windows
side (e.g. `cp obj/betaflight_*_ETHANF405.hex /mnt/d/Drone/drone_PCB/`).

> On Windows/WSL your D: drive is at `/mnt/d/` inside Ubuntu, so the config for
> this project is at `/mnt/d/Drone/drone_PCB/betaflight_target/ETHANF405/config.h`.

Re-run only step 2.4 whenever you edit `config.h`.

---

## 3. Flash the board (once it arrives)

1. Open Betaflight Configurator → **Firmware Flasher** tab.
2. Put the board in DFU: hold **BOOT0**, plug in USB, release. Windows shows a
   "STM32 BOOTLOADER" device. First time, run **Zadig** and set that device's
   driver to **WinUSB**, or Configurator won't see it.
3. Tick **Full chip erase** (first flash only).
4. Click **Load Firmware [Local]**, pick your `ETHANF405…hex`.
5. **Flash Firmware.** Wait for the verify to finish.

---

## 4. Bring-up order (props off, ESC unplugged)

Do these in order — each depends on the one before. Full detail lives in
`drone_fc_project_context_v3.md` §Build Order step 10; the short version:

1. **Continuity-beep the ESC harness FIRST** (before any power): VBAT + both GND
   pads from the mated cable to the ESC XT60. This is the mandatory check that
   the connector isn't mirrored — a reversed cable puts 16.8 V on a 3.3 V GPIO.
   (context v3, remaining item #1.)
2. **Bridge JP10** — the solder jumper between the TLV733P output and the
   `+3V3_IMU` net. It's a `SolderJumper_2_Open` footprint, so it ships open and
   the IMU's VDD (BMI270 pin 8) is dead until you blob it. Symptom if missed:
   board enumerates fine, no gyro detected.
3. **Rail smoke test:** bench PSU, current-limited, no MCU load first — confirm
   5 V and both 3.3 V rails before trusting the board. Measure `+3V3_IMU`
   specifically, downstream of JP10.
4. **Connect in Configurator** (normal USB, no BOOT0). Land on the **Setup** tab.
5. **Move the board** — the 3D model should follow. That proves the IMU + SPI +
   firmware all work. Then fix `GYRO_1_ALIGN` in config.h: the committed value is
   a placeholder guessed for the old ICM-42605, so expect to change it.
6. **Ports tab:** enable **Serial RX** on UART1 (your i-BUS receiver).
7. **Receiver tab:** power the RX, move TX sticks, confirm channels map right.
8. **Modes tab:** assign an **ARM** switch.
9. **Motors tab (still props off):** set protocol **DShot600**, spin each motor
   with the sliders, fix direction/order here (not in copper). This is where the
   S1–S4 physical order gets sorted.
10. **CLI checks for this custom board:** run `resource`, `timer`, and
    `dma show all` — confirm all four motors have a DMA stream and nothing clashes
    with SPI1/SPI2, then `save`. (The `config.h` timer/DMA row for **PB10** is
    best-effort and flagged to verify here; PA3+PB10 share TIM2.)
11. **Calibrate:** accelerometer (board flat), then `vbat_scale` (~110 start) and
    the current-meter scale by bench sweep — both are unknown until measured.
12. **Set the blackbox log rate** — see the flash note below. In CLI:
    `set blackbox_sample_rate = 1/4` then `save`. Skipping this gives you ~22
    seconds of log per erase.
13. Failsafe, then — and only then — props on.

Optional after it flies: flash **Bluejay** onto the ESC via ESC-Configurator for
bidirectional-DShot RPM filtering (BLHeli_S has no serial telemetry).

---

## Quick reference — what's pinned in config.h (matches the CubeMX board pinout)

| Function | Pin(s) |
|---|---|
| Gyro/Acc | **Bosch BMI270**, SPI1 (PA5/PA6/PA7), CS PC4, INT PC3 |
| Flash (blackbox) | **GD25Q16E — 2 MB**, SPI2 (SCK PB13 / **MISO PC2** / MOSI PB15), CS PB12 |
| Motors 1–4 | PB0, PB1, **PA3, PB10** (TIM3_CH3/CH4, TIM2_CH4/CH3) |
| Receiver | UART1 (TX PA9 / RX PA10), i-BUS |
| Current ADC | **PA2** (ADC1_IN2) — confirmed (zener-clamped) |
| VBAT ADC | PA1 — **verify a divider exists**, may be no-connect |
| LED / Beeper | **PC13** (via 330Ω, dim — see note) / PC5 |
| PA8, PB3 | spare test-point pads, no firmware function |

Full canonical pin table with net names: `../VERIFIED_PINOUT.md`.

### Gyro note (changed 2026-07-30)

The IMU is the **Bosch BMI270**, not the ICM-42605 the earlier docs describe —
the TDK 426xx family went reel-only in single quantities. Driver defines are
`USE_GYRO_SPI_BMI270` / `USE_ACC_SPI_BMI270`. There is no pin-compatible
alternate part for this footprint; the old "swap to ICM-42688-P" note no longer
applies.

Two things this changes at bring-up:

- **Max PID loop is 3.2 kHz**, not 8 kHz. Betaflight clocks the BMI270 gyro at a
  3.2 kHz ODR (chip max 6.4 kHz). Setting 8k in Configurator won't do what you
  expect.
- **`GYRO_1_ALIGN` must be re-derived** at step 4 below. The value in `config.h`
  was guessed for the 42605's die orientation and the BMI270 sits on a different
  footprint rotation, so treat it as unknown.

If the Setup tab reports **no gyro detected**, suspect the SPI1 connection or an
unbridged **JP10** before you suspect the chip: the BMI270 driver uploads an
~8 KB init blob over SPI at boot, so any marginal link fails as a hard
"not present" rather than as noisy data.

### Blackbox flash note — the fitted chip is 2 MB, not 16 MB

**U3 is a GigaDevice GD25Q16E (LCSC C2904431) = 16 Mbit = 2 MB.** The BOM called
for a 128 Mbit part; the wrong one was ordered. It's being kept.

**No firmware change is needed.** `USE_FLASH_W25Q128FV` in `config.h` is only a
gate that pulls in Betaflight's generic `m25p16` driver (via `common_post.h`),
and that driver detects chips by JEDEC ID at runtime. Our chip is in its table:

```c
// GigaDevice GD25Q16E
{ 0xC84015, 104, 50, 32, 256 },   // 32 sectors x 256 pages x 256 B = 2 MB
```

Configurator will report **2 MB** on the Blackbox tab. That is correct, not a
fault. Don't chase it.

**What you must do:** budget the log rate. Roughly 30 KB/s per kHz of logging
rate for a standard quad field set:

| `blackbox_sample_rate` | Log rate @ 3.2 kHz PID | ~Bitrate | Time to fill 2 MB |
|---|---|---|---|
| `1/1` | 3.2 kHz | ~96 KB/s | **~22 s** — unusable |
| `1/2` | 1.6 kHz | ~48 KB/s | ~44 s |
| **`1/4`** | **800 Hz** | **~24 KB/s** | **~87 s** — use this |
| `1/8` | 400 Hz | ~12 KB/s | ~175 s |

800 Hz logging still resolves everything below 400 Hz, which covers the motor
and frame noise peaks that filter tuning actually depends on. Tuning runs are
30–60 s regardless; the practical loss is that you can't log a whole pack.

To claw back more space, disable fields you have no hardware for — this board
has no GPS, no mag, no baro, and no RSSI pin. Run `get blackbox` in the CLI to
list the exact setting names for your firmware version (they're a bitmask
exposed as individual `blackbox_disable_*` booleans), then turn off the ones
that apply. Leave `debug` on only while you're actually reading a debug mode.

**Upgrade path** if 90 seconds stops being enough: GD25Q128E (C2758105) or
BY25Q128ES (C22471255). Both are in the same `m25p16` JEDEC table, both are
SOIC-8 208mil with identical pinout, so it's a hot-air swap with no firmware
change.

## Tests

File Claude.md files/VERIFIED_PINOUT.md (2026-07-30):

# ETHANF405 — VERIFIED Pin Map (canonical)

**Source of truth for firmware.** Verified against the KiCad schematic
(2026-07-23) and the STM32CubeMX report "STM32 Program". This is the **as-ordered
board** — where this table disagrees with older docs (`drone_fc_project_context_v3.md`,
audits), **this table wins**. The board is fabricated; pins are not changing.

MCU: STM32F405RGT6, LQFP-64. HSE 8 MHz.

## Active functions

| Function | Pin | Peripheral / net | Notes |
|---|---|---|---|
| Motor 1 | PB0 | TIM3_CH3 | net `TIM3_CH3-M1` |
| Motor 2 | PB1 | TIM3_CH4 | net `TIM3_CH4-M2` |
| Motor 3 | PA3 | TIM2_CH4 | net `TIM2_CH4-M3` |
| Motor 4 | PB10 | TIM2_CH3 | net `TIM2_CH3-M4` |
| Gyro SCK | PA5 | SPI1_SCK | **BMI270** (U7) — see IMU note below |
| Gyro MISO | PA6 | SPI1_MISO | |
| Gyro MOSI | PA7 | SPI1_MOSI | |
| Gyro CS | PC4 | GPIO (net `IMU_nCS`) | |
| Gyro INT | PC3 | EXTI3 (net `IMU_EXTI3`) | data-ready |
| Flash SCK | PB13 | SPI2_SCK | **GD25Q16E, 2 MB** — see note below |
| Flash MISO | PC2 | SPI2_MISO | **on PC2, not PB14** |
| Flash MOSI | PB15 | SPI2_MOSI | |
| Flash CS | PB12 | GPIO (net `/CS`) | |
| Current sense | PA2 | ADC1_IN2 | net `CurrentM1`, D1 zener clamp to GND |
| Receiver TX | PA9 | USART1_TX | |
| Receiver RX | PA10 | USART1_RX | FS-iA6B i-BUS in |
| USB D− | PA11 | USB_OTG_FS_DM | |
| USB D+ | PA12 | USB_OTG_FS_DP | |
| SWDIO | PA13 | SWD | debug header |
| SWCLK | PA14 | SWD | debug header |
| Buzzer | PC5 | GPIO → 2N7002 + D8 (1N914) flyback + R20 10k | active buzzer |
| Status LED | PC13 | GPIO → R19 330Ω | see WARNING below |
| Crystal | PH0 / PH1 | RCC_OSC_IN/OUT | 8 MHz HSE |
| BOOT0 | 60 | boot strap | |
| BOOT1 | PB2 | boot strap | |
| NRST | 7 | reset | |
| VCAP_1 / VCAP_2 | 31 / 47 | C12 / C13, 2.2µF each | core reg |

## IMU — BMI270, not ICM-42605 (changed 2026-07-30)

The gyro is a **Bosch BMI270** (U7, LCSC C2836813, footprint
`drone_lib:LGA-14_L3.0-W2.5-P0.50-BR`). The 426xx family went reel-only / OOS in
single quantities. The **STM32 pin map above did not change** — only the chip and
its footprint. Pad-to-net wiring verified against BMI270 datasheet rev 1.3
Table 22 (p.145):

| Pad | Name | Net | Datasheet (SPI 4-wire) |
|---|---|---|---|
| 1 | SDO | `MISO` → PA6 | SDO ✓ |
| 2 / 3 | ASDx / ASCx | `+3V3` (= VDDIO) | VDDIO ✓ — must **not** go to GND |
| 4 | INT1 | `EXTI3` → PC3 | INT1 ✓ |
| 5 | VDDIO | `+3V3` (main AP2112K rail) | ✓ |
| 6 / 7 | GNDIO / GND | `GND` | ✓ |
| 8 | VDD | `+3V3_IMU` (quiet TLV733P rail, **via JP10**) | ✓ |
| 9 / 10 / 11 | INT2 / OCSB / OSDO | unconnected | DNC ✓ |
| 12 | CSB | `IMU_nCS` → PC4, R3 10k → +3V3 | CSB ✓ |
| 13 | SCx | `SPI1_SCK` → PA5 | SCK ✓ |
| 14 | SDx | `MOSI` → PA7 | SDI ✓ |

Decoupling is C14 100nF (VDD) + C15 100nF (VDDIO) — correct for the BMI270, and
deliberately **not** the 2.2µF/0.1µF/10nF arrangement the 426xx required.

Firmware consequences: driver = `USE_GYRO_SPI_BMI270` / `USE_ACC_SPI_BMI270`;
gyro ODR 3.2 kHz in Betaflight (chip max 6.4 kHz) so the **PID loop ceiling is
3.2 kHz, not 8 kHz**; SPI clock ceiling 10 MHz (was 24 MHz); the driver uploads an
~8 KB init blob at every boot; the chip boots in I2C mode and needs a CSB rising
edge to enter SPI (R3 holds CSB high through POR, BF's driver toggles CS).

## Blackbox flash — 2 MB, not 16 MB

U3 as fitted is a **GigaDevice GD25Q16E (C2904431), 16 Mbit = 2 MB**. The BOM
specified a 128 Mbit part; the wrong one was ordered. Keeping it.

No firmware change needed: `USE_FLASH_W25Q128FV` only gates Betaflight's generic
`m25p16` driver (via `common_post.h`), and that driver detects by JEDEC ID at
runtime. Our chip is in its table as `{ 0xC84015, 104, 50, 32, 256 }` =
32 sectors × 256 pages × 256 B = 2,097,152 bytes. **Configurator reporting 2 MB
is correct, not a fault.**

Cost is log duration: at ~30 KB/s per kHz of logging rate, 3.2 kHz fills it in
~22 s. **Set `blackbox_sample_rate = 1/4`** (800 Hz, ~87 s) at bring-up. Full
table and field-disable advice in `../betaflight_target/BUILD.md`.

## Unresolved / confirm at bring-up

- **PA1 (ADC1_IN2 region / ADC1_IN1):** CubeMX allocated PA1 as an ADC input
  (intended battery-voltage sense), but the schematic view shows it at/near
  no-connect. **Battery VOLTAGE sensing may not exist on this board.** Confirm
  whether a divider actually lands on PA1. If not: Betaflight gets current but no
  pack voltage (no voltage sag/alarms). Current sense (PA2) is confirmed present.
- **Status LED on PC13 — WARNING:** PC13 is in the F405 backup/power-switch
  domain and can only sink ~3 mA (DS8626), so the LED will be dim. It works, but
  it's not a normal GPIO. PB8 (the pin the old docs called for) is **not
  connected** on this board.
- **PA8 (pin 41):** broken out to a pad, labelled only `PA8`, no assigned
  function. Spare/test point. (CubeMX had it as EXTI8; hardware = spare.)
- **PB3 (pin 55):** broken out, labelled `PB3`. Spare/test point.
- **JP10 (`SolderJumper_2_Open`)** sits between the TLV733P output and the
  `+3V3_IMU` net, so it ships **open** and the BMI270's VDD is unpowered until
  it's solder-bridged. Bridge it before first power-up. Symptom if missed: board
  enumerates over USB, "no gyro detected."
- **`GYRO_1_ALIGN`** in `config.h` is a placeholder guessed for the old ICM-42605.
  The BMI270 has different die axes and a different footprint rotation — re-derive
  it on the bench, don't assume it carried over.

## Not connected (spare)

PA0, PA1(see above), PA4, PA15, PC0, PC1, PC6–PC12, PC14, PC15, PB4–PB9, PB11,
PB14, PD2.

## Firmware mapping consequences

- Motors → `MOTOR1..4_PIN = PB0, PB1, PA3, PB10`. PA3+PB10 share TIM2 (different
  channels); PB0+PB1 share TIM3. Confirm DShot DMA with `dma show all` at bring-up.
- `ADC_CURR_PIN PA2` confirmed. `ADC_VBAT_PIN PA1` unconfirmed (may be absent).
- `LED0_PIN PC13` (not PB8).
- Physical motor S1–S4 order is set in Configurator after the spin test, not here.

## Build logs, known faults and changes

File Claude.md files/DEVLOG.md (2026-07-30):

# Development Log — Custom STM32F405 Flight Controller

A running engineering log for the drone flight-controller PCB project. Entries are
dated and describe what was done, why, and what it unblocked. Newest entries are
added at the **bottom**.

> Log started 2026-07-11. Entries dated before that were reconstructed from git
> history, the dated design-review documents, and the versioned project-context
> notes, so early dates reflect when the work landed in the repo/docs rather than
> a live daily log.

**Project:** ~60×60 mm, 4-layer, STM32F405RGT6 flight controller for a 4S freestyle
drone. Runs Betaflight (custom target). Single-sided SMD, self-reflow. Mates to an
existing Flycolor Raptor BLS-04 4-in-1 ESC (no BEC → onboard buck required).

---

## 2026-05-20 — Project kickoff / architecture v1
- Defined the goal: design a flight controller from scratch as a bench/résumé
  project around the STM32F405 with native Betaflight support.
- Initial power architecture assumed an external Matek MBEC6S for 5 V; IMU
  candidate and rail strategy scoped. Target battery: 6S.
- Committed initial project skeleton and README.

## 2026-06-09 — First design audit (v3 context)
- Ran a full design audit (`FC_audit_2026-06-09.md`) and consolidated all decisions
  into `drone_fc_project_context_v3.md` (part numbers, pin map, power tree).

## 2026-06-16 — ESC harness pinout verified
- Obtained the manufacturer pinout diagram for the BLS-04 10-pin SH1.0 harness and
  cross-checked it against the v1 candidate. Locked the signal order
  (TX, current, S1–S4, NC, VBAT, GND, GND). Flagged a mandatory pre-power
  continuity check to rule out a mirrored connector.

## 2026-06-23 — Major architecture decisions locked
- Board grows to ~60×60 mm (oversized bench board, retains 30.5 mm M3 mount).
- Assembly changed to self-reflow: bare 4-layer PCB + frameless stencil, all SMD
  single-sided (top), leaded paste + hotplate, hot-air for the LGA IMU.
- **Power architecture change:** dropped the external MBEC6S; the FC now carries its
  own onboard buck (TPS5430DDAR, VBAT→5V/3A) because the BLS-04 ESC has no BEC.
- IMU resolved: stay with ICM-42605 (Betaflight-preferred, available, shares the
  426xx LGA-14 footprint with the ICM-42688-P alternate). BMI270 evaluated and
  rejected for new designs.

## 2026-06-26 — Schematic capture in progress
- Buck (TPS5430) fully wired; both LDOs (AP2112K main + TLV733P quiet IMU rail)
  wired; USB-C wired; IMU power wired.
- Decided the IMU rail split: VDD on the quiet +3V3_IMU, VDDIO on the main +3V3 so
  digital I/O switching noise stays off the gyro supply.
- Receiver locked: FlySky FS-iA6B over i-BUS straight into UART1 RX (non-inverted;
  S.BUS rejected — no internal F405 inverter).

## 2026-06-27 — Independent design review
- Second-pass review (`FC_independent_review_2026-06-27.md`) to pressure-test the
  power tree and pin assignments.

## 2026-06-28 — Battery → 4S, motor remap
- Switched target battery from 6S to 4S (14.8 V nom / 16.8 V full). Buck output
  inductor revised to 15 µH per the TI datasheet for this Vin/Vout; input-cap
  voltage rating requirement relaxed.
- Motor remap: moved M4 PB7→PB5 (TIM3_CH2) to clear a DMA1 stream clash with
  SPI2_RX (blackbox). Final: M1=PB0, M2=PB1, M3=PB6, M4=PB5. Verified against
  RM0090 DMA tables.
- Schematic review captured in `FC_schematic_review_2026-06-28.md`.

## 2026-07-10 — Continued schematic work
- Iterated on the MCU support circuitry and I/O sheet (multiple project backups
  saved during editing).

## 2026-07-11 — Schematic completed and verified; entering layout
- Completed the remaining analog/protection and debug circuitry:
  - **Current-sense clamp** on the ESC current line: 1 kΩ series + 3.3 V zener to
    GND, with the ADC (PC1) tapped between the resistor and the clamp.
  - **VBAT divider**: 100 kΩ / 10 kΩ + 100 nF from raw +BATT to PC2 (0.091 ratio;
    16.8 V → 1.53 V), enabling battery-voltage telemetry.
  - **SWD debug header** (J1): 3V3 / SWDIO (PA13) / SWDCLK (PA14) / GND / NRST, as
    insurance for flashing/recovery if USB DFU fails.
  - **Power-good LED** on +3V3 with a series resistor; removed an earlier LED from
    the quiet +3V3_IMU rail to avoid loading the gyro supply.
  - Completed the buck: added the 220 µF polymer output cap, 10 nF BOOT cap, and
    the 10k/3.24k feedback divider tied to the output.
- Ran a full pin-by-pin netlist verification directly against the KiCad files:
  MCU core, IMU (all 14 pins), flash, USB + ESD, dual LDOs, ORing diodes, boot/
  reset, current sense, VBAT divider, and SWD all verified correct.
- **Open before fab:** confirm ESC connector orientation with a continuity-beep
  test (the schematic numbers CN1 reverse to the manufacturer diagram — correct
  only if the connector mates reversed); run ERC to zero; keep the project off the
  synced drive to avoid save-corruption.
- Repo hygiene: committed the schematic edits to git (branch `main`).
- **Next:** PCB layout — 4-layer, solid L2 ground under the IMU, tight buck
  switching loop kept away from the IMU and analog ADC traces, matched USB pair.

## 2026-07-23 — Custom Betaflight target created + pinout verified against fab board
- Wrote the custom Betaflight target `betaflight_target/ETHANF405/config.h` plus
  a build/flash/bring-up guide (`betaflight_target/BUILD.md`).
- **Reconciled the firmware pin map against the as-ordered board** (CubeMX report
  + KiCad schematic), which diverged from the v3 context doc's pin table. The
  board is fabricated, so the schematic is now the source of truth. Captured it in
  the new canonical `VERIFIED_PINOUT.md` and referenced it from `CLAUDE.md`.
- Key corrections vs. the old docs: motors are PB0/PB1/**PA3/PB10**
  (TIM3_CH3/CH4, TIM2_CH4/CH3), flash SPI2 **MISO on PC2** (not PB14), ADC current
  on **PA2** (VBAT on PA1 unconfirmed — possibly no-connect → maybe no pack-voltage
  telemetry), status LED on **PC13** via 330Ω (dim, ~3mA backup-domain limit; PB8
  unconnected). PA8/PB3 are spare pads.
- **Open before flashing:** confirm PA1 VBAT divider exists; verify motor DShot
  DMA (`dma show all`) since PA3+PB10 share TIM2 and PB0+PB1 share TIM3.
- Unblocks: building the `.hex` (`make configs && make ETHANF405`) ahead of the
  board arriving.

## 2026-07-30 — IMU changed: ICM-42605 → Bosch BMI270 (sourcing-forced); docs + firmware reconciled

- **Why:** the entire TDK InvenSense 426xx family (ICM-42605, ICM-42688-P,
  IIM-42652) became unobtainable in single quantities — reel-only MOQ 1000+ at
  LCSC, OOS/backordered at DigiKey and Mouser. This **reverses the 2026-06-23
  decision** to stay with the 42605 and the rejection of the BMI270 recorded in
  that entry.
- **New part:** Bosch **BMI270**, U7, LCSC **C2836813**, ~$0.82–1.79, buy-1 in
  stock. Betaflight gyro define `BMI270`.
- **Not a drop-in.** Same 2.5×3.0mm LGA-14 outline, completely different pinout →
  new footprint (`drone_lib:LGA-14_L3.0-W2.5-P0.50-BR`) and every IMU net
  re-routed. Decoupling simplified to **100nF at VDD + 100nF at VDDIO** (the
  2.2µF/0.1µF/10nF set was a 426xx requirement). Unused-pin strapping inverted:
  ASDx(2)/ASCx(3) now go to **VDDIO and must not be grounded**, and
  INT2(9)/OCSB(10)/OSDO(11) are left **unconnected**, where the 42605's RESV pins
  went to GND.
- **Power architecture absorbed the swap with zero change** — VDD still on the
  quiet TLV733P `+3V3_IMU` rail, VDDIO still on the main AP2112K `+3V3`. This is
  the concrete payoff of the 2026-06-26 rail-split decision: a forced sourcing
  change cost a footprint and a re-route, not a power redesign.
- **Verified this session:** all 14 pads checked against BMI270 datasheet rev 1.3
  Table 22 (p.145) — wiring is correct. IMU nets confirmed routed in the PCB
  (SPI1_SCK 22 segments, IMU_nCS 18, EXTI3 15, MOSI 9, MISO 7). The production
  export in `Drone_PCB_FC/production/` already carries U7 = BMI270, so the fab
  package is the BMI270 board.
- **Firmware updated:** `config.h` swapped from `USE_GYRO/ACC_SPI_ICM42605` to
  `USE_GYRO/ACC_SPI_BMI270`. As shipped it would have failed WHO_AM_I and
  reported "no gyro detected." Behavioural consequences documented in the file:
  **PID loop ceiling drops 8 kHz → 3.2 kHz** (BF clocks the BMI270 gyro at a
  3.2 kHz ODR; chip max 6.4 kHz), **SPI clock ceiling 24 MHz → 10 MHz**, driver
  uploads an ~8 KB init blob at every boot, and the chip boots in I2C mode
  needing a CSB rising edge to enter SPI (R3's 10k pull-up + BF's CS toggle
  handle this).
- **`GYRO_1_ALIGN` flagged as unknown** — the committed `CW0_DEG` was guessed for
  the 42605's die orientation; the BMI270 has different die axes *and* a
  different footprint rotation. Must be re-derived on the bench.
- **Accepted tradeoff:** the BMI270 ships uncalibrated, which is exactly why
  Betaflight discourages it for new designs (few-percent attitude error).
  Irrelevant for Acro freestyle, visible in Angle/Horizon and level trim.
- **Docs reconciled:** `CLAUDE.md`, `VERIFIED_PINOUT.md` (new § IMU with the
  pad-by-pad table), `drone_fc_project_context_v3.md` (superseding header box +
  IMU/power/BOM sections, old text struck through rather than deleted),
  `schematic_capture_walkthrough.md` Block 6 (rewritten), `betaflight_target/BUILD.md`,
  and `datasheets/lcsc.txt` (marked stale, points at `libs/lcsc.txt`).
- **New bring-up item found while auditing: JP10.** The `+3V3_IMU` rail reaches
  the BMI270's VDD through solder jumper **JP10**, which is a
  `SolderJumper_2_Open` footprint — it ships open. Unbridged, the board
  enumerates over USB and reports no gyro. Added to the BUILD.md bring-up
  sequence ahead of the rail smoke test.
- **Found while auditing — BOM drift across three files.** `production/bom.csv`
  (2026-07-19, the export the boards were ordered from) lists U3 =
  **GD25Q16ETIGR C2904431, a 16 Mbit part**, plus TPS5430DDAR (C9864) and
  L2 = C354622 (22µH), where `Drone_PCB_FC_LCSC_BOM.csv` says BY25Q128ESSIG
  (128 Mbit), TPS5450 and 15µH C83374. Flash resolved below; **TPS5430-vs-5450
  and the 22µH-vs-15µH inductor are still open** — confirm which was actually
  ordered before populating the buck.
- **Also fixed:** the LCSC BOM had the IMU as U6; schematic, PCB and production
  files all say **U7**. Corrected in the BOM.
- **Next:** bridge JP10, confirm the buck parts, then bench bring-up per
  BUILD.md §4.

## 2026-07-30 — Blackbox flash is 2 MB, not 16 MB (wrong part ordered) — keeping it

- **What happened:** U3 as ordered and fitted is a **GigaDevice GD25Q16E
  (C2904431) — 16 Mbit = 2 MB**. The BOM specified a 128 Mbit part
  (BY25Q128ESSIG, C22471255). Wrong part made it onto the order; caught while
  reconciling the three BOM files during the BMI270 doc pass.
- **No firmware change required** — verified against Betaflight master, not
  assumed. `USE_FLASH_W25Q128FV` is not a chip selector; it's only a gate that
  pulls in the generic `m25p16` driver via `common_post.h`:
  `#if (USE_FLASH_W25M512 || USE_FLASH_W25Q128FV || USE_FLASH_PY25Q128HA) && !USE_FLASH_M25P16 -> define USE_FLASH_M25P16`.
  That driver detects chips by **JEDEC ID at runtime**, and ours is in its
  table: `{ 0xC84015, 104, 50, 32, 256 }` — GigaDevice GD25Q16E, 32 sectors ×
  256 pages × 256 B = **2,097,152 bytes**. Configurator will report 2 MB and
  that is correct behaviour, not a fault.
- **Decision: keep the 2 MB part.** The cost is log duration, not function.
  At ~30 KB/s per kHz of logging rate: 3.2 kHz → ~22 s (unusable), 1.6 kHz →
  ~44 s, **800 Hz → ~87 s**. Tuning runs are 30–60 s regardless, and 800 Hz
  still resolves everything below 400 Hz, which is where the motor/frame noise
  peaks that filter tuning depends on actually live. The real loss is the
  ability to log a whole pack.
- **Mandatory bring-up step added:** `set blackbox_sample_rate = 1/4`. Without
  it the log fills in ~22 seconds. Added to BUILD.md §4 as step 12.
- Documented the full rate table plus field-disable advice (no GPS/mag/baro/RSSI
  on this board) in `betaflight_target/BUILD.md`, and the reasoning inline in
  `config.h` next to the misleading-but-correct `USE_FLASH_W25Q128FV` define so
  nobody "fixes" it later.
- **Upgrade path if 90 s stops being enough:** GD25Q128E (C2758105) or
  BY25Q128ES (C22471255). Both are in the same `m25p16` JEDEC table, both
  SOIC-8 208mil with identical pinout — hot-air swap, no firmware change.

---

### Log format (for future entries)
```
## YYYY-MM-DD — <short milestone title>
- What I did and why.
- Any decision made + the reason / tradeoff.
- What it unblocked, or what's next.
```

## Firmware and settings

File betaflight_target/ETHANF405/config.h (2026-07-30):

/*
 * ETHANF405 — custom Betaflight target for the STM32F405RGT6 flight controller.
 *
 * PIN MAP MATCHES THE AS-ORDERED BOARD, taken from the STM32CubeMX report
 * "STM32 Program" (2026-07-23). Where CubeMX and the older schematic docs
 * disagreed, CubeMX (the board you actually ordered) wins.
 *
 * Build with the betaflight/config workflow: drop this at
 * config/configs/ETHANF405/config.h, then  make configs && make ETHANF405
 * See BUILD.md for the full procedure.
 *
 * Anything marked  >>> VERIFY  must be confirmed on the bench at bring-up.
 */

#pragma once

#define FC_TARGET_MCU     STM32F405

#define BOARD_NAME        ETHANF405
#define MANUFACTURER_ID   CUST          // local build only

/* ---------------------------------------------------------------------------
 * IMU / gyro — Bosch BMI270 on SPI1 (U7, LCSC C2836813).
 *
 * CHANGED 2026-07-30: was ICM-42605. The whole TDK 426xx family went reel-only
 * / OOS in single quantities, so the board was re-spun onto the BMI270. It is
 * NOT a drop-in — same 2.5x3.0mm LGA-14 outline, completely different pinout —
 * but that was absorbed in the schematic/PCB (footprint ...-BR, every IMU net
 * re-routed). Wiring verified against BMI270 datasheet rev 1.3 Table 22 (p.145).
 * Nothing below this comment changes for the pin map; only the driver.
 *
 * Behavioural differences vs the 42605, all handled by the BF driver but worth
 * knowing at bring-up:
 *   - Gyro ODR is 3.2 kHz in Betaflight (chip max 6.4 kHz), NOT 8 kHz. The PID
 *     loop ceiling is 3.2k. Don't try to force 8k in Configurator.
 *   - SPI clock ceiling 10 MHz (BMI270_MAX_SPI_CLK_HZ) vs 24 MHz on the 42605.
 *   - The driver uploads an ~8 KB init blob over SPI at every boot. A marginal
 *     SPI1 connection shows up as "no gyro detected", not as noise.
 *   - The chip powers up in I2C mode and only switches to SPI on a CSB rising
 *     edge. R3 (10k to +3V3) holds CSB high through POR; the BF driver toggles
 *     CS to make the transition. Relevant only if you ever drive it from bare
 *     STM32 code.
 *   - The BMI270 ships uncalibrated (this is why BF discourages it for new
 *     designs). Irrelevant in Acro; costs you a few percent attitude accuracy
 *     in Angle/Horizon and on level trim.
 * ------------------------------------------------------------------------- */
#define USE_GYRO
#define USE_ACC
#define USE_GYRO_SPI_BMI270
#define USE_ACC_SPI_BMI270

/* ---------------------------------------------------------------------------
 * Blackbox flash — SPI2.
 *
 * FITTED PART IS **GigaDevice GD25Q16E (LCSC C2904431) — 16 Mbit = 2 MB**, not
 * the 128 Mbit part the BOM called for. Ordered by mistake; kept deliberately.
 *
 * The define below looks wrong but IS correct. Betaflight's flash detection is
 * JEDEC-ID based at runtime, and `USE_FLASH_W25Q128FV` is only a gate that
 * pulls in the generic m25p16 driver via common_post.h:
 *
 *     #if (defined(USE_FLASH_W25M512) || defined(USE_FLASH_W25Q128FV) \
 *          || defined(USE_FLASH_PY25Q128HA)) && !defined(USE_FLASH_M25P16)
 *     #define USE_FLASH_M25P16
 *     #endif
 *
 * That driver's device table contains our chip:
 *     // GigaDevice GD25Q16E
 *     { 0xC84015, 104, 50, 32, 256 },   // 32 sectors x 256 pages x 256 B = 2 MB
 * so it enumerates and works with no code change. Do NOT "fix" this to some
 * GD25Q16 define — no such define exists.
 *
 * CONSEQUENCE: 2 MB, i.e. 1/8th the intended log space. Rule of thumb is
 * ~30 KB/s of log per kHz of logging rate for a standard quad field set:
 *
 *     3.2 kHz (1/1)  ~96 KB/s  ->  ~22 s   <- unusable
 *     1.6 kHz (1/2)  ~48 KB/s  ->  ~44 s
 *     800 Hz  (1/4)  ~24 KB/s  ->  ~87 s   <- recommended
 *
 * So set `blackbox_sample_rate = 1/4` at bring-up (see BUILD.md). 800 Hz still
 * resolves everything below 400 Hz, which covers the noise peaks that matter
 * for filter and PID tuning. Tuning runs are 30-60 s anyway; this board just
 * can't log a whole pack. Upgrade path if that ever bites: GD25Q128E
 * (C2758105) or BY25Q128ES (C22471255) — both in the same m25p16 table, both
 * identical SOIC-8 208mil pinout, hot-air swap.
 * ------------------------------------------------------------------------- */
#define USE_FLASH
#define USE_FLASH_W25Q128FV     // gate for the m25p16 driver; actual chip is GD25Q16E, 2 MB

/* ---------------------------------------------------------------------------
 * Pin assignments — from the CubeMX pinout of the ordered board
 * ------------------------------------------------------------------------- */

/* Motors (CubeMX: PB0=TIM3_CH3, PB1=TIM3_CH4, PA3=TIM2_CH4, PB10=TIM2_CH3).
 * Betaflight motor 1..4 -> these pins; physical S1..S4 order is sorted in
 * Configurator after the spin test, no code change. Timer/DMA rows below. */
#define MOTOR1_PIN           PB0
#define MOTOR2_PIN           PB1
#define MOTOR3_PIN           PA3
#define MOTOR4_PIN           PB10

/* Gyro (SPI1) */
#define SPI1_SCK_PIN         PA5
#define SPI1_SDI_PIN         PA6        // MISO
#define SPI1_SDO_PIN         PA7        // MOSI
#define GYRO_1_SPI_INSTANCE  SPI1
#define GYRO_1_CS_PIN        PC4        // CubeMX GPIO_Output
#define GYRO_1_EXTI_PIN      PC3        // CubeMX GPIO_EXTI3

/* Blackbox flash (SPI2) — note MISO is on PC2 on this board, not PB14 */
#define SPI2_SCK_PIN         PB13
#define SPI2_SDI_PIN         PC2        // MISO  (CubeMX SPI2_MISO = PC2)
#define SPI2_SDO_PIN         PB15       // MOSI
#define FLASH_SPI_INSTANCE   SPI2
#define FLASH_CS_PIN         PB12       // CubeMX GPIO_Output

/* Receiver — FlySky FS-iA6B i-BUS on UART1 RX */
#define UART1_TX_PIN         PA9
#define UART1_RX_PIN         PA10

/* ADC — schematic-verified: CURRENT sense is on PA2 (net CurrentM1, D1 zener).
 * PA1 was allocated in CubeMX for battery-voltage sense, but the schematic
 * shows it at/near no-connect, so VBAT sensing may not exist on this board.
 * >>> VERIFY PA1: if there's no divider, delete ADC_VBAT_PIN — you'll have
 * current but no pack-voltage reading. */
#define ADC_CURR_PIN         PA2        // ADC1_IN2 — confirmed
#define ADC_VBAT_PIN         PA1        // >>> VERIFY: may be no-connect (no vbat sense)
#define ADC_INSTANCE         ADC1

/* Status LED — schematic shows the LED on PC13 (via R19 330Ω), NOT PB8 (PB8 is
 * unconnected on this board). WARNING: PC13 is in the F405 backup/power-switch
 * domain and can only sink ~3 mA (DS8626), so the LED will be dim but works. */
#define LED0_PIN             PC13

/* Beeper — PC5 GPIO driving a 2N7002 low-side switch + active buzzer (D8 1N914
 * flyback, R20 10k). Low-side FET => pin HIGH = buzzer ON = active-high, so
 * BEEPER_INVERTED is intentionally NOT defined. >>> VERIFY at bring-up. */
#define BEEPER_PIN           PC5
// #define BEEPER_INVERTED

/*
 * PA8 (pin 41) and PB3 (pin 55) are broken out to pads with no assigned
 * function on the schematic — spare/test points. Nothing to map in firmware.
 */

/* ---------------------------------------------------------------------------
 * Timer + DMA mapping for the motor outputs.
 *   PB0 / PB1 / PA3 rows are copied VERBATIM from OMNIBUSF4 (known-good DSHOT
 *   DMA). PB10 (TIM2_CH3) is unique to this board — best-effort, confirm below.
 *   >>> VERIFY at bring-up: in CLI run `resource`, `timer`, `dma show all`;
 *   confirm all four motors get a DMA stream with no clash against SPI1 (gyro)
 *   or SPI2 (flash), then `save`. Configurator's Motors/Timers/DMA tabs do the
 *   same with a GUI. Note PA3+PB10 share TIM2 (different channels) — fine for
 *   DShot, but that's exactly what `dma show all` verifies.
 * ------------------------------------------------------------------------- */
#define TIMER_PIN_MAPPING \
    TIMER_PIN_MAP( 0, PB0,  2, 0 ) \
    TIMER_PIN_MAP( 1, PB1,  2, 0 ) \
    TIMER_PIN_MAP( 2, PA3,  1, 1 ) \
    TIMER_PIN_MAP( 3, PB10, 1, 0 )

/* ---------------------------------------------------------------------------
 * Defaults
 * ------------------------------------------------------------------------- */
#define SYSTEM_HSE_MHZ       8

/* Gyro orientation — depends on how the chip faces vs the frame front.
 * >>> VERIFY at bring-up: watch the Setup-tab 3D model, adjust until it tracks.
 * This value is a PLACEHOLDER and is very likely wrong since the IMU changed:
 * the BMI270 has different die axes AND sits on a different footprint
 * orientation (-BR) than the 42605 this was originally guessed for. Re-derive
 * it on the bench, don't assume CW0 carried over. */
#define GYRO_1_ALIGN         CW0_DEG

#define DEFAULT_BLACKBOX_DEVICE      BLACKBOX_DEVICE_FLASH
#define DEFAULT_CURRENT_METER_SOURCE CURRENT_METER_ADC
#define DEFAULT_VOLTAGE_METER_SOURCE VOLTAGE_METER_ADC

/* Receiver defaults — i-BUS on UART1. Still enable "Serial RX" for UART1 in
 * Configurator > Ports at bring-up. */
#define DEFAULT_RX_FEATURE   FEATURE_RX_SERIAL
#define SERIALRX_PROVIDER    SERIALRX_IBUS
#define SERIALRX_UART        SERIAL_PORT_USART1

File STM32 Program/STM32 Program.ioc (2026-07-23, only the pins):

Mcu.UserName=STM32F405RGTx
PA1.Signal=ADCx_IN1
PA10.Signal=USART1_RX
PA11.Signal=USB_OTG_FS_DM
PA12.Signal=USB_OTG_FS_DP
PA13.Signal=SYS_JTMS-SWDIO
PA14.Signal=SYS_JTCK-SWCLK
PA2.Signal=ADCx_IN2
PA3.Signal=S_TIM2_CH4
PA5.Signal=SPI1_SCK
PA6.Signal=SPI1_MISO
PA7.Signal=SPI1_MOSI
PA8.Signal=GPXTI8
PA9.Signal=USART1_TX
PB0.Signal=S_TIM3_CH3
PB1.Signal=S_TIM3_CH4
PB10.Signal=S_TIM2_CH3
PB12.Signal=GPIO_Output
PB13.Signal=SPI2_SCK
PB15.Signal=SPI2_MOSI
PC2.Signal=SPI2_MISO
PC3.Signal=GPXTI3
PC4.Signal=GPIO_Output
PC5.Signal=GPIO_Output
PH0-OSC_IN.Signal=RCC_OSC_IN
PH1-OSC_OUT.Signal=RCC_OSC_OUT

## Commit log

2026-06-27 Initial commit: STM32F405 flight controller
    [Blackbox-flash.kicad_sch, Drone_PCB_FC.csv, Drone_PCB_FC.kicad_pcb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]
2026-06-28 almost done with the schmatic design
    [Blackbox-flash.kicad_sch, Drone_PCB_FC.kicad_sch, IMU-ICM42605-p.kicad_sch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]
2026-07-10 vbat divider, current-sense clamp, power LEDs
    [Blackbox-flash.kicad_sch, Drone_PCB_FC.kicad_pcb, Drone_PCB_FC.kicad_sch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]
2026-07-13 starting the PCB layout
    [Blackbox-flash.kicad_sch, Drone_PCB_FC.kicad_pcb, IMU-ICM42605-p.kicad_sch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]
2026-07-16 pcb is 'done' but i think i messed up the IMU so ill fix later
    [Drone_PCB_FC.kicad_pcb, IMU-ICM42605-p.kicad_sch, IO.kicad_sch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]
2026-07-17 3rd try on the PCB, still need to triple check before I order, and I NEED to check stock because i might need a redesign
    [Drone_PCB_FC.csv, Drone_PCB_FC.kicad_pcb, Drone_PCB_FC_LCSC_BOM.csv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]
2026-07-19 Ordered the PCB now i have to wait and see if i waisted 130 dollars
    [Blackbox-flash.kicad_sch, Drone_PCB_FC.kicad_pcb, Drone_PCB_FC_LCSC_BOM.csv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]
2026-07-19 docs: update README with new hardware choices and project status
    Updates the README to reflect the shift from ICM-42605 to Bosch BMI270,
    change of blackbox flash to BOYAMICRO BY25Q128ES, and buck regulator to
    TPS5450. Also updates the project status, battery spec to 4S, and
    incorporates new details about design for bring-up and notable
    engineering decisions.
2026-07-23 updating some stuff
    [5inch_frame_bottom.scad, 5inch_frame_bottom.stl, Drone_PCB_FC.kicad_pcb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]
2026-07-30 updated the BOM and README
    [Drone_PCB_FC_LCSC_BOM.csv]
2026-09-07 I have the test bench working. now i need the frame
2026-10-23 Reorganize repo and add v2 board work
    - Add the v2 KiCad project (Drone_PCB_FC_V2/).
    - Add firmware target files, built hex images, blackbox logs and CLI dumps.
    - Add new custom library parts (3D shapes and footprints) for the v2 board.
    - Move the BOM, bring-up checklist and placement notes into Drone_PCB_FC/.
    - Stop tracking CLAUDE.md, the local .ai/ notes and the STM32 Program/
    CubeMX project. These files stay on disk but are now in .gitignore.
    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
